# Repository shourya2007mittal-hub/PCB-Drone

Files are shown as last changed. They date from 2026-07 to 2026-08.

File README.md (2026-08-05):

# PCB-Drone



So I made a custom PCB based on Esp32 . It holds an IMU and a Barometer for control . It has a normal 4 Motor Layout 2 motors will move  clock wise and 2 will be  anti-clock wise direction. Same direction motor will be diagonally apposite to each other. It have  used a 3.7V battery for power and a boot converter so that I can provide 5V to the Motors as we are using  ESP32 so we could controle it by our phone through bluetooth  .I have also design a web based controller , So that you could connect and controle the Bionic-Bird through your phone.

So I have a USB-C and battery pin (3.7V) then it is commonly connected to power with diodes for reverse polarity then It goes to a 3.3V voltage regulator (AP63203WU) with Reverse Polarity Protection and Pi Filter for sensors and ESp32  . and 5V regulator (MT3608) for motors . Then 3.3v it goes to IMU (MPU-6050) Barometer (BMP280) then through I2c these data are transferred to ESP32 where computation takes place and through Logic-Level Enhancement Mode MOSFET(AO3400A) circuit it amplifies  the PWN signal to 5V for the motors to work  

## Features

- Base on ESP32 Module
- Has IMU (MPU_6050)
- Has a Barometer (BMP280)
- Uses 4 8520 Motors 

## Components BOM

### 1. JLCPCB Manufacturing & Assembly Services
| Charge Description | Details / Notes | Cost ($) |
| :--- | :--- | :---: |
| **Components Cost** | 26 Matched Part Lines | $64.35 |
| **Setup Fee** | SMT Line Assembly Setup | $25.56 |
| **Stencil Fee** | SMT Laser Stencil | $8.21 |
| **Feeders Loading Fee** | Component Feeder Setup | $33.66 |
| **SMT Assembly** | Automated SMT Placement | $1.23 |
| **Hand-Soldering Labor Fee** | Through-hole / Manual Soldering | $3.58 |
| **Manual Assembly** | Specialized Component Insertion | $0.46 |
| **X-Ray Inspection** | BGA / QFN Joint Verification | $3.28 |
| **Packaging Fee** | Protective ESD Packaging | $0.50 |
| **Engineering Fee** | DFM / CAM File Verification | $4.00 |
| **Via Covering** | Tent / Plugged Vias | $0.00 |
| **PCB Fabrication Board Fee** | Raw Printed Circuit Board Cost | $9.90 |
| **PCB Shipping** | Express Courier to Destination | $11.53 |

---

### 2. External Hardware & Accessories
| Item | Description / Details | Qty | Link | Cost ($) |
| :--- | :--- | :---: | :---: | :---: |
| **8520 Coreless Motor** | Magnetic Micro Coreless Motor Set (2x CW, 2x CCW) | 1 Set | [Robu.in Link](https://robu.in/product/8520-magnetic-micro-coreless-motor-for-micro-quadcopters-2xcw-2xccw/) | $4.93 |
| **3.7V Battery** | KP Original 802540 1200mAh Single-Cell LiPo Battery | 1 Pcs | [Zbotic Link](https://zbotic.in/product/kp-original-802540-1200mah-3-7vsingle-cell-rechargeable-lipo-battery/) | $3.46 |

---

## 🧩 Complete Component Bill of Materials (BOM)

| Designator | Description / Value | Footprint | Qty | Price ($) | Part Details / Link |
| :--- | :--- | :--- | :---: | :---: | :--- |
| **C2** | 47uF 450V Electrolytic | 0201 | 2 | $1.333 | [KM476M450K25RR0VH2FP0](https://jlcpcb.com/partdetail/3127-KM476M450K25RR0VH2FP0/C2746) |
| **C3, C11, C18, C19** | 10uF 6.3V X5R | 0201 | 40 | $1.172 | [CL10A106MQ8NNNC](https://jlcpcb.com/partdetail/2043-CL10A106MQ8NNNC/C1691) |
| **C4, C13, C14** | 100nF 10V X5R | 0201 | 40 | $0.292 | [GRM033R61A104KE15D](https://jlcpcb.com/partdetail/MurataElectronics-GRM033R61A104KE15D/C76934) |
| **C5, C6** | 22uF 10V X5R | 0201 | 16 | $5.0256 | [1206X226K100NT](https://jlcpcb.com/partdetail/2211-1206X226K100NT/C1859) |
| **C9, C10, C12** | 0.1uF 10V X5R | 0201 | 40 | $0.236 | [0201X104K100NT](https://jlcpcb.com/partdetail/270391-0201X104K100NT/C284966) |
| **C7, C8, C15, C16** | 50nF Capacitors | 0201 | 8 | $6.532 | [LHC503SA2K0042NWB](https://jlcpcb.com/partdetail/launchip-LHC503SA2K0042NWB/C49233446) |
| **C1X1 - C6X1** | 1uF / 100nF Caps | 0805 | 22 | $0.3982 | [GZ2012D220TF](https://jlcpcb.com/partdetail/Sunlord-GZ2012D220TF/C1009) |
| **D1, D3** | LED Indicator | 0201 | 8 | $0.5448 | [XL0201SURC](https://jlcpcb.com/partdetail/XINGLIGHT-XL0201SURC/C3646923) |
| **D2** | Diode | 0201 | 2 | $0.3944 | [HIR204C](https://jlcpcb.com/partdetail/EverlightElec-HIR204C/C5118) |
| **D4, D5, D6, D7** | Schottky Diode | 0201 | 20 | $0.038 | [0201WMJ010JTEE](https://jlcpcb.com/partdetail/25797-0201WMJ010JTEE/C25054) |
| **F1** | Polyfuse | 0201 | 20 | $0.038 | [0201WMJ010JTEE](https://jlcpcb.com/partdetail/25797-0201WMJ010JTEE/C25054) |
| **D8** | 1N4001 Diode | DO-41 | 4 | $0.0776 | [1N4001](https://jlcpcb.com/partdetail/49200031-1N4001/C47018536) |
| **L1** | 2.2uH Power Inductor | 0201 | 20 | $0.750 | [CY43_22UH](https://jlcpcb.com/partdetail/SHOUHAN-CY43_22UH/C2929416) |
| **L2** | 4.7uH Inductor | 0603 | 20 | $0.414 | [SDFL1608Q4R7KTF](https://jlcpcb.com/partdetail/Sunlord-SDFL1608Q4R7KTF/C1034) |
| **Q1** | AO3401A P-Ch MOSFET | SOT-23 | 6 | $0.5688 | [AO3401A](https://jlcpcb.com/partdetail/Alpha_OmegaSemicon-AO3401A/C15127) |
| **Q2, Q3, Q4, Q5** | AO3400A N-Ch MOSFET | SOT-23 | 12 | $1.008 | [AO3400A](https://jlcpcb.com/partdetail/Alpha_OmegaSemicon-AO3400A/C20917) |
| **R1, R2** | 33 Ohm Resistor | 0201 | 20 | $0.062 | [0201WMJ0330TEE](https://jlcpcb.com/partdetail/416306-0201WMJ0330TEE/C423356) |
| **R3, R4** | 50K Resistor | 0201 | 6 | $0.7632 | [GL3549](https://jlcpcb.com/partdetail/10622-GL3549/C10083) |
| **R6, R7** | 1K Resistor | 0201 | 20 | $0.050 | [0201WMF1001TEE](https://jlcpcb.com/partdetail/259895-0201WMF1001TEE/C270365) |
| **R8, R10, R12, R14** | 100 Ohm Resistor | 0201 | 20 | $0.056 | [RC01W1000FT](https://jlcpcb.com/partdetail/288566-RC01W1000FT/C304499) |
| **R9, R11, R13, R15** | 10K Resistor | 0201 | 20 | $0.086 | [CR0201FH1002G](https://jlcpcb.com/partdetail/LIZElec-CR0201FH1002G/C100126) |
| **R1_1, R2_1** | 10K / 100 Ohm | 0805 | 6 | $0.5364 | [FSMD050_0805R](https://jlcpcb.com/partdetail/FuzetecTech-FSMD050_0805R/C181350) |
| **U1** | MT3608 Boost Regulator | SOT-23-6 | 5 | $0.5665 | [MT3608](https://jlcpcb.com/partdetail/XI_AN_AerosemiTech-MT3608/C84817) |
| **U2** | AP63203WU Buck Regulator | TSOT-23-6 | 2 | $2.2268 | [AP63203QWU7](https://jlcpcb.com/partdetail/DiodesIncorporated-AP63203QWU7/C5248536) |
| **U3** | MPU-6050 6-Axis IMU Sensor | QFN-24 | 2 | $29.0122 | [MPU6050](https://jlcpcb.com/partdetail/TDKInvenSense-MPU6050/C24112) |
| **U4** | BMP280 Barometric Pressure Sensor | LGA-8 | 2 | $5.2442 | [BMP388 / BMP280](https://jlcpcb.com/partdetail/BoschSensortec-BMP388/C779278) |
| **U5** | ESP32-S3-WROOM-1 Wi-Fi/BT MCU | Module | 2 | $10.327 | [ESP32_S3_WROOM_1N16R8](https://jlcpcb.com/partdetail/3198300-ESP32_S3_WROOM_1N16R8/C2913202) |
| **J1** | USB Type-C Receptacle 16P | USB-C | - | - | Hand Assembly / Manual |
| **J2** | Pin Header Connector | JST-EH 2.5mm | - | - | Through Hole |
| **M1, M2, M3, M4** | Motor Drive Outputs | 1x02 Pin Header | - | - | Through Hole |
| **SW1, SW2** | Push Button Switches | PTS810 | - | - | SMT / Manual |

---

---

## 📊 Summary & Total Cost

| Category | Total Cost (USD) |
| :--- | :---: |
| **PCBA Manufacturing & Components (26 Items)** | **$154.73** |
| **PCB Shipping (JLCPCB)** | **$11.53** |
| **External Motors (8520 Coreless Motor Set)** | **$4.93** |
| **3.7V LiPo Battery (1200mAh)** | **$3.46** |
| **Grand Total** | **`$174.65`** |

### Schematic



###  PCB Design




###  3D Design



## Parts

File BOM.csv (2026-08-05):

Top design | Comment | footprint | quantitty | total price | product link
Top Designator | Comment | Footprint | Qty | Total Price ($) | Product link
C2 | 47uf | 0201 | 2 | 1.333 | https://jlcpcb.com/partdetail/3127-KM476M450K25RR0VH2FP0/C2746
C3 | 10uf | 0201 | 20 | 0.586 | https://jlcpcb.com/partdetail/2043-CL10A106MQ8NNNC/C1691
C11,C18,C19 | 10uf | 0201 | 20 | 0.586 | https://jlcpcb.com/partdetail/2043-CL10A106MQ8NNNC/C1691
C4 | 100nf | 0201 | 20 | 0.146 | https://jlcpcb.com/partdetail/MurataElectronics-GRM033R61A104KE15D/C76934
C13,C14 | 100nf | 0201 | 20 | 0.146 | https://jlcpcb.com/partdetail/MurataElectronics-GRM033R61A104KE15D/C76934
C5 | 22u | 0201 | 8 | 2.5128 | https://jlcpcb.com/partdetail/2211-1206X226K100NT/C1859
C6 | 22uf | 0201 | 8 | 2.5128 | https://jlcpcb.com/partdetail/2211-1206X226K100NT/C1859
C10,C9 | 0.1uf | 0201 | 20 | 0.118 | https://jlcpcb.com/partdetail/270391-0201X104K100NT/C284966
C12 | 0.1uf | 0201 | 20 | 0.118 | https://jlcpcb.com/partdetail/270391-0201X104K100NT/C284966
C15,C16,C7,C8 | 50nf | 0201 | 8 | 6.532 | https://jlcpcb.com/partdetail/launchip-LHC503SA2K0042NWB/C49233446
C1X1,C2X1,C3X1,C4X1,C5(1UF)1,C6(100NF)1 | C | 0805 | 22 | 0.3982 | https://jlcpcb.com/partdetail/Sunlord-GZ2012D220TF/C1009
D1,D3 | LED | 0201 | 8 | 0.5448 | https://jlcpcb.com/partdetail/XINGLIGHT-XL0201SURC/C3646923
D2 | D | 0201 | 2 | 0.3944 | https://jlcpcb.com/partdetail/EverlightElec-HIR204C/C5118
D4,D5,D6,D7 | D_Schottky | 0201 | 20 | 0.038 | https://jlcpcb.com/partdetail/25797-0201WMJ010JTEE/C25054
F1 | Polyfuse | 0201 | 20 | 0.038 | https://jlcpcb.com/partdetail/25797-0201WMJ010JTEE/C25054
D8 | 1N4001 | D_DO-41_SOD81_P5.08mm_Vertical_KathodeUp | 4 | 0.0776 | https://jlcpcb.com/partdetail/49200031-1N4001/C47018536
L1 | 2.2uh | 0201 | 20 | 0.75 | https://jlcpcb.com/partdetail/SHOUHAN-CY43_22UH/C2929416
L2 | 4.7uf | 0603 | 20 | 0.414 | https://jlcpcb.com/partdetail/Sunlord-SDFL1608Q4R7KTF/C1034
Q1 | AO3401A | SOT-23 | 6 | 0.5688 | https://jlcpcb.com/partdetail/Alpha_OmegaSemicon-AO3401A/C15127
Q2,Q3,Q4,Q5 | AO3400A | SOT-23 | 12 | 1.008 | https://jlcpcb.com/partdetail/Alpha_OmegaSemicon-AO3400A/C20917
R1,R2 | 33R | 0201 | 20 | 0.062 | https://jlcpcb.com/partdetail/416306-0201WMJ0330TEE/C423356
R3,R4 | 50K | 0201 | 6 | 0.7632 | https://jlcpcb.com/partdetail/10622-GL3549/C10083
R6,R7 | 1K | 0201 | 20 | 0.05 | https://jlcpcb.com/partdetail/259895-0201WMF1001TEE/C270365
R10,R12,R14,R8 | 100R | 0201 | 20 | 0.056 | https://jlcpcb.com/partdetail/288566-RC01W1000FT/C304499
R11,R13,R15,R9 | 10KR | 0201 | 20 | 0.086 | https://jlcpcb.com/partdetail/LIZElec-CR0201FH1002G/C100126
R1(10K)1,R2(100R)1 | R | 0805 | 6 | 0.5364 | https://jlcpcb.com/partdetail/FuzetecTech-FSMD050_0805R/C181350
U1 | MT3608 | SOT-23-6 | 5 | 0.5665 | https://jlcpcb.com/partdetail/XI_AN_AerosemiTech-MT3608/C84817
U2 | AP63203WU | TSOT-23-6 | 2 | 2.2268 | https://jlcpcb.com/partdetail/DiodesIncorporated-AP63203QWU7/C5248536
U3 | MPU-6050 | InvenSense_QFN-24_4x4mm_P0.5mm | 2 | 29.0122 | https://jlcpcb.com/partdetail/TDKInvenSense-MPU6050/C24112
U4 | BMP280 | Bosch_LGA-8_2x2.5mm_P0.65mm_ClockwisePinNumbering | 2 | 5.2442 | https://jlcpcb.com/partdetail/BoschSensortec-BMP388/C779278
U5 | ESP32-S3-WROOM-1 | ESP32-S3-WROOM-1 | 2 | 10.327 | https://jlcpcb.com/partdetail/3198300-ESP32_S3_WROOM_1N16R8/C2913202
J1 | USB_C_Receptacle_USB2.0_16P | USB_C_Receptacle_G-Switch_GT-USB-7010ASV
J2 | Conn_01x02_Pin | JST_EH_B2B-EH-A_1x02_P2.50mm_Vertical
M1,M2,M3,M4 | Motor_DC | PinHeader_1x02_P2.54mm_Vertical
SW1,SW2 | SW_Push | SW_SPST_PTS810
Components (26 items) | JLCPCB Assembly Order Components | - | 26 | 64.35 | -
Setup Fee | Assembly Setup Fee | - | 1 | 25.56 | -
Stencil | SMT Stencil Fee | - | 1 | 8.21 | -
Feeders Loading fee | Feeder Loading Fee | - | 1 | 33.66 | -
SMT Assembly | SMT Assembly Fee | - | 1 | 1.23 | -
Hand-soldering labor fee | Labor Fee | - | 1 | 3.58 | -
Manual Assembly | Manual Assembly Fee | - | 1 | 0.46 | -
X-Ray Inspection | Inspection Fee | - | 1 | 3.28 | -
Packaging fee | Packaging Fee | - | 1 | 0.5 | -
Engineering fee | Engineering Fee | - | 1 | 4.0 | -
Via Covering | Via Covering Fee | - | 1 | 0.0 | -
Board | PCB Manufacturing Board Fee | - | 1 | 9.9 | -
PCB Shipping |  |  | - | 11.53 | JLCPCB
8520 Coreless Motor |  |  | 1 Set (of 4) | 4.93 | https://robu.in/product/8520-magnetic-micro-coreless-motor-for-micro-quadcopters-2xcw-2xccw/?gad_source=1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
3.7V battery |  |  | 1 | 3.46 | https://zbotic.in/product/kp-original-802540-1200mah-3-7vsingle-cell-rechargeable-lipo-battery/?gad_source=1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
Total |  |  |  | 174.65

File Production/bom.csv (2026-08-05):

Designator | Footprint | Quantity | Value | LCSC Part #
C10, C9 | 0201 | 2 | 0.1uf
C11, C18, C19 | 0201 | 3 | 10 uf
C12 | 0201 | 1 | 0.1 uf
C13, C14 | 0201 | 2 | 100 nf
C15, C16, C7, C8 | 0201 | 4 | 50nf
C1X1, C2X1, C3X1, C4X1, C5(1UF)1, C6(100NF)1 | 0805 | 6 | C
C2 | 0201 | 1 | 47uf
C3 | 0201 | 1 | 10uf
C4 | 0201 | 1 | 100nf
C5 | 0201 | 1 | 22u
C6 | 0201 | 1 | 22uf
D1, D3 | 0201 | 2 | LED
D2 | 0201 | 1 | D
D4, D5, D6, D7 | 0201 | 4 | D_Schottky
D8 | D_DO-41_SOD81_P5.08mm_Vertical_KathodeUp | 1 | 1N4001
F1 | 0201 | 1 | Polyfuse
J1 | USB_C_Receptacle_G-Switch_GT-USB-7010ASV | 1 | USB_C_Receptacle_USB2.0_16P
J2 | JST_EH_B2B-EH-A_1x02_P2.50mm_Vertical | 1 | Conn_01x02_Pin
L1 | 0201 | 1 | 2.2uh
L2 | 0603 | 1 | 4.7uf
M1, M2, M3, M4 | PinHeader_1x02_P2.54mm_Vertical | 4 | Motor_DC
Q1 | SOT-23 | 1 | AO3401A
Q2, Q3, Q4, Q5 | SOT-23 | 4 | AO3400A
R1, R2 | 0201 | 2 | 33 R
R1(10K)1, R2(100R)1 | 0805 | 2 | R
R10, R12, R14, R8 | 0201 | 4 | 100R
R11, R13, R15, R9 | 0201 | 4 | 10K R
R3, R4 | 0201 | 2 | 50K
R6, R7 | 0201 | 2 | 1K
SW1, SW2 | SW_SPST_PTS810 | 2 | SW_Push
U1 | SOT-23-6 | 1 | MT3608
U2 | TSOT-23-6 | 1 | AP63203WU
U3 | InvenSense_QFN-24_4x4mm_P0.5mm | 1 | MPU-6050
U4 | Bosch_LGA-8_2x2.5mm_P0.65mm_ClockwisePinNumbering | 1 | BMP280
U5 | ESP32-S3-WROOM-1 | 1 | ESP32-S3-WROOM-1

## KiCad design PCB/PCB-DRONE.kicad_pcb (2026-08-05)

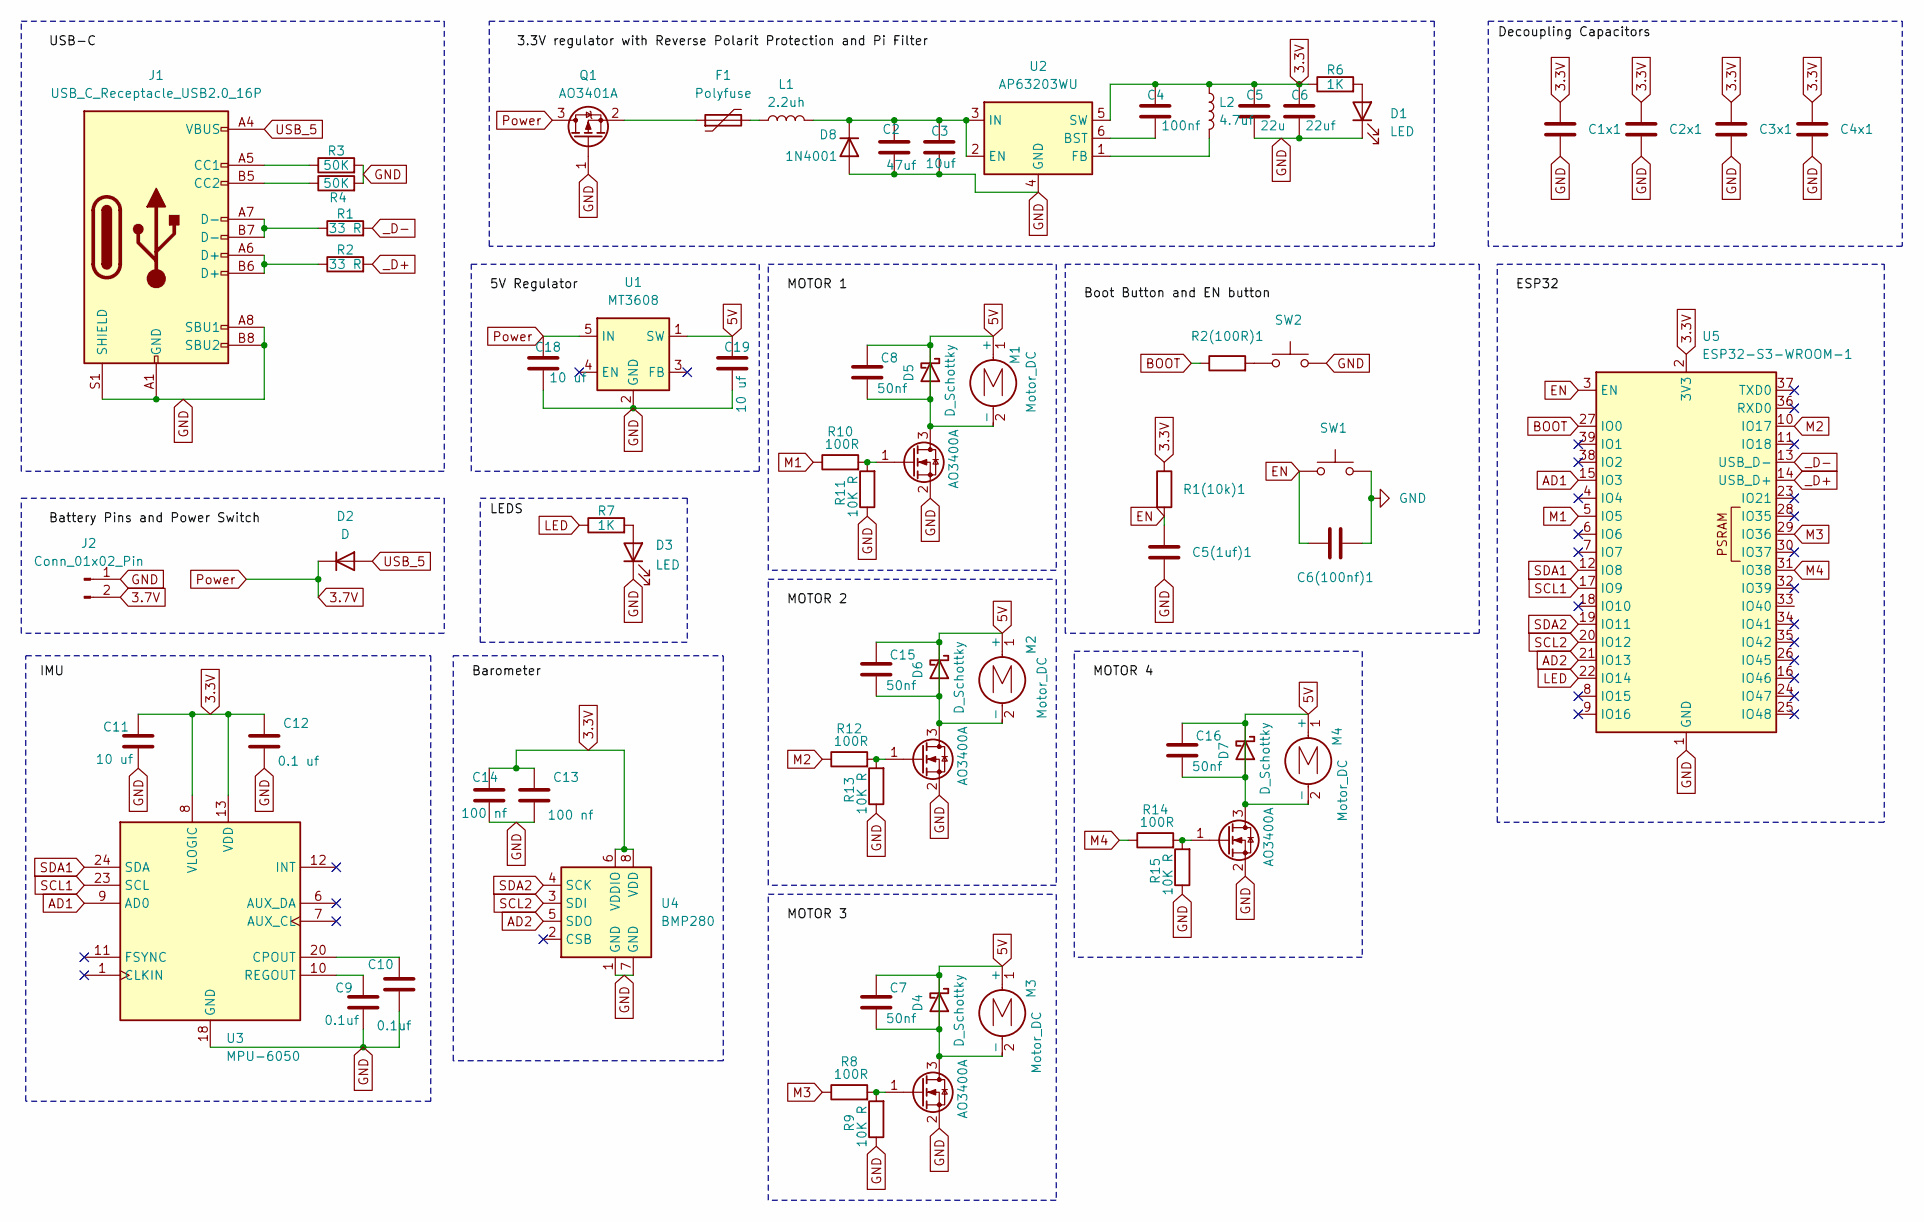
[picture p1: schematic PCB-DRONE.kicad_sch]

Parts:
C1x1, C2x1, C3x1, C4x1, C5(1uf)1, C6(100nf)1: C; C_0805_2012Metric
C2: 47uf; C_0201_0603Metric
C3: 10uf; C_0201_0603Metric
C4: 100nf; C_0201_0603Metric
C5: 22u; C_0201_0603Metric
C6: 22uf; C_0201_0603Metric
C7, C8, C15, C16: 50nf; C_0201_0603Metric
C9, C10: 0.1uf; C_0201_0603Metric
C11, C18, C19: 10 uf; C_0201_0603Metric
C12: 0.1 uf; C_0201_0603Metric
C13, C14: 100 nf; C_0201_0603Metric
D1, D3: LED; LED_0201_0603Metric
D2: D; D_0201_0603Metric
D4, D5, D6, D7: D_Schottky; D_0201_0603Metric
D8: 1N4001; D_DO-41_SOD81_P5.08mm_Vertical_KathodeUp
F1: Polyfuse; C_0201_0603Metric
J1: USB_C_Receptacle_USB2.0_16P; USB_C_Receptacle_G-Switch_GT-USB-7010ASV
J2: Conn_01x02_Pin; JST_EH_B2B-EH-A_1x02_P2.50mm_Vertical
L1: 2.2uh; L_0201_0603Metric
L2: 4.7uf; L_0603_1608Metric
M1, M2, M3, M4: Motor_DC; PinHeader_1x02_P2.54mm_Vertical
Q1: AO3401A; SOT-23
Q2, Q3, Q4, Q5: AO3400A; SOT-23
R1, R2: 33 R; R_0201_0603Metric_Pad0.64x0.40mm_HandSolder
R1(10k)1, R2(100R)1: R; R_0805_2012Metric
R3, R4: 50K; R_0201_0603Metric_Pad0.64x0.40mm_HandSolder
R6, R7: 1K; R_0201_0603Metric_Pad0.64x0.40mm_HandSolder
R8, R10, R12, R14: 100R; R_0201_0603Metric
R9, R11, R13, R15: 10K R; R_0201_0603Metric
SW1, SW2: SW_Push; SW_SPST_PTS810
U1: MT3608; SOT-23-6
U2: AP63203WU; TSOT-23-6
U3: MPU-6050; InvenSense_QFN-24_4x4mm_P0.5mm
U4: BMP280; Bosch_LGA-8_2x2.5mm_P0.65mm_ClockwisePinNumbering
U5: ESP32-S3-WROOM-1

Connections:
3.3V: C1x1.1, C2x1.1, C3x1.1, C4.1, C4x1.1, C5.1, C6.1, C11.1, C12.1, C13.1, C14.1, L2.1, R1(10k)1.1, R6.1, U2.5 (SW), U3.8 (VLOGIC), U3.13 (VDD), U4.6 (VDDIO), U4.8 (VDD), U5.2 (3V3)
3.7V: C18.1, D2.1 (K), J2.2, Q1.3 (D), U1.5 (IN)
5V: C7.1, C7.2, C8.1, C8.2, C15.1, C15.2, C16.1, C16.2, C19.1, D4.1 (K), D4.2 (A), D5.1 (K), D5.2 (A), D6.1 (K), D6.2 (A), D7.1 (K), D7.2 (A), M1.1 (+), M1.2 (-), M2.1 (+), M2.2 (-), M3.1 (+), M3.2 (-), M4.1 (+), M4.2 (-), Q2.3 (D), Q3.3 (D), Q4.3 (D), Q5.3 (D), U1.1 (SW)
AD1: U3.9 (AD0), U5.15 (IO3)
AD2: U4.5 (SDO), U5.21 (IO13)
BOOT: R2(100R)1.1, U5.27 (IO0)
EN: C5(1uf)1.1, C6(100nf)1.1, R1(10k)1.2, SW1.1, U5.3 (EN)
GND: C1x1.2, C2.2, C2x1.2, C3.2, C3x1.2, C4x1.2, C5.2, C5(1uf)1.2, C6.2, C6(100nf)1.2, C9.2, C10.2, C11.2, C12.2, C13.2, C14.2, C18.2, C19.2, D1.1 (K), D3.1 (K), D8.2 (A), J1.A1 (GND), J1.A8 (SBU1), J1.A12 (GND), J1.B1 (GND), J1.B8 (SBU2), J1.B12 (GND), J1.S1 (SHIELD), J2.1, Q1.1 (G), Q2.2 (S), Q3.2 (S), Q4.2 (S), Q5.2 (S), R3.2, R4.2, R9.1, R11.1, R13.1, R15.1, SW1.2, SW2.2, U1.2 (GND), U2.4 (GND), U3.18 (GND), U4.1 (GND), U4.7 (GND), U5.1 (GND), U5.40 (GND), U5.41 (GND)
LED: R7.1, U5.22 (IO14)
M1: R10.1, U5.5 (IO5)
M2: R12.1, U5.10 (IO17)
M3: R8.1, U5.29 (IO36)
M4: R14.1, U5.31 (IO38)
unnamed: D1.2 (A), R6.2
unnamed: D3.2 (A), R7.2
unnamed: C2.1, C3.1, D8.1 (K), L1.2, U2.2 (EN), U2.3 (IN)
unnamed: F1.2, L1.1
unnamed: J1.A5 (CC1), R3.1
unnamed: J1.B5 (CC2), R4.1
unnamed: J1.A6 (D+), J1.B6 (D+), R2.1
unnamed: J1.A7 (D-), J1.B7 (D-), R1.1
unnamed: F1.1, Q1.2 (S)
unnamed: Q2.1 (G), R8.2, R9.2
unnamed: Q3.1 (G), R10.2, R11.2
unnamed: Q4.1 (G), R12.2, R13.2
unnamed: Q5.1 (G), R14.2, R15.2
unnamed: R2(100R)1.2, SW2.1
unnamed: C4.2, U2.6 (BST)
unnamed: L2.2, U2.1 (FB)
unnamed: C10.1, U3.20 (CPOUT)
unnamed: C9.1, U3.10 (REGOUT)
SCL1: U3.23 (SCL), U5.17 (IO9)
SCL2: U4.3 (SDI), U5.20 (IO12)
SDA1: U3.24 (SDA), U5.12 (IO8)
SDA2: U4.4 (SCK), U5.19 (IO11)
USB_5: D2.2 (A), J1.A4 (VBUS), J1.A9 (VBUS), J1.B4 (VBUS), J1.B9 (VBUS)
_D+: R2.2, U5.14 (USB_D+)
_D-: R1.2, U5.13 (USB_D-)

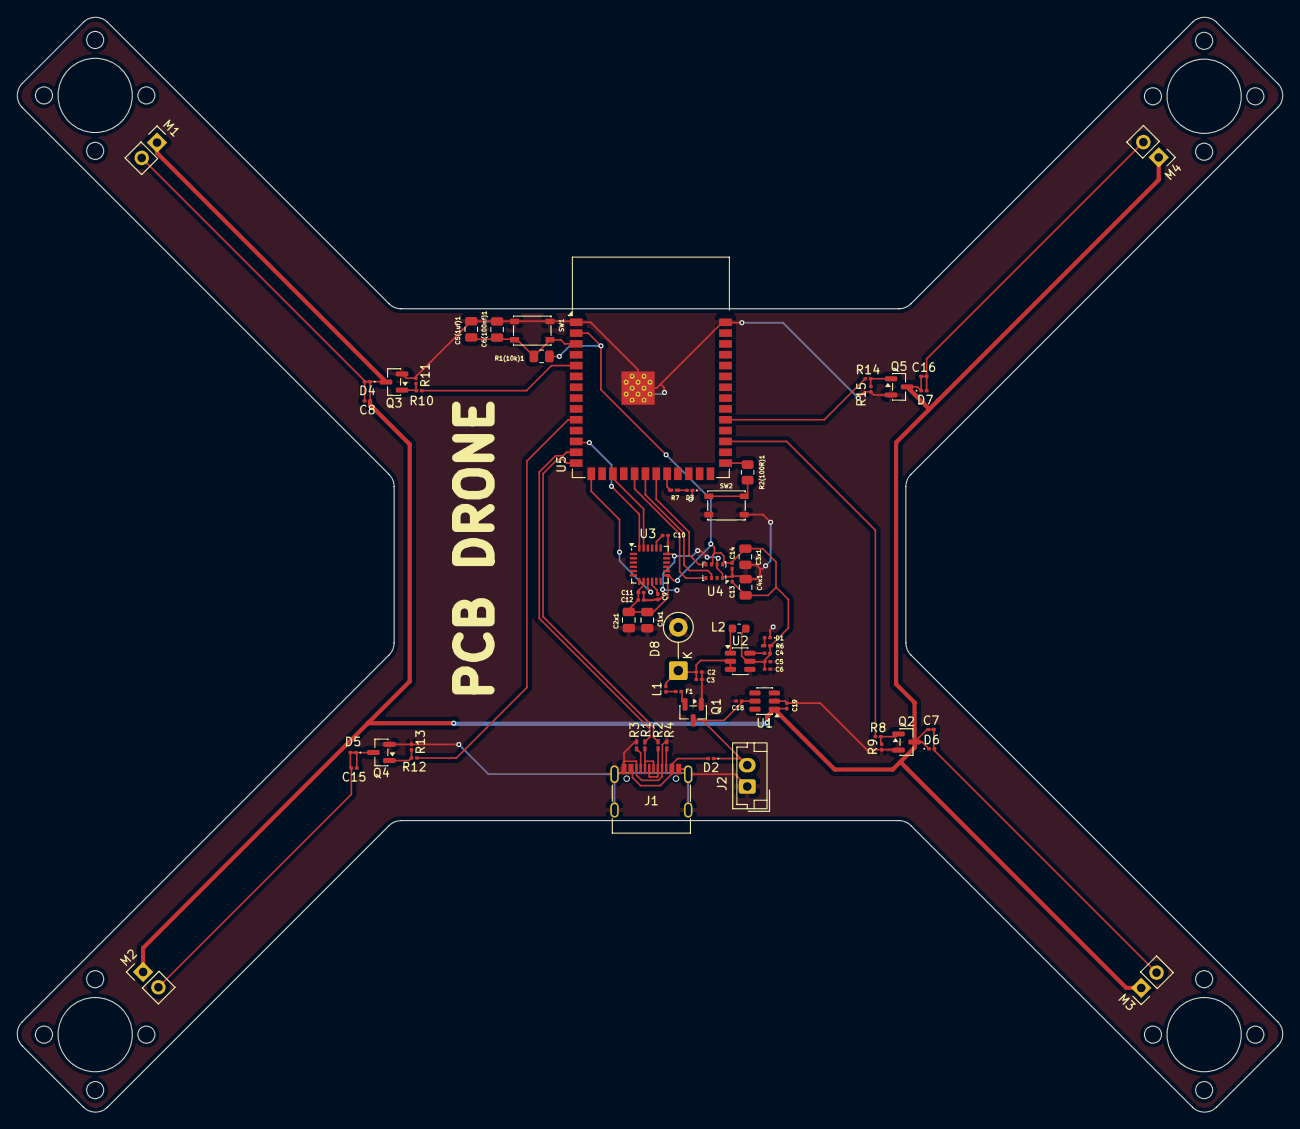
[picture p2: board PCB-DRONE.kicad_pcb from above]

Board: 2 copper layers, 148.3 x 128.3 mm, 68 parts (0 on the bottom side), 38 nets.

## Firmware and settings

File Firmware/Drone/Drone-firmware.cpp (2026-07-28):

#include <Wire.h>
#include <Adafruit_MPU6050.h>
#include <Adafruit_BMP280.h>
#include <NimBLEDevice.h>

// --- PIN DEFINITIONS ---
#define PIN_M1 5
#define PIN_M2 17
#define PIN_M3 36
#define PIN_M4 37
#define PIN_LED 14

#define SDA_IMU 12
#define SCL_IMU 17 // Shared pin in schematic, note hardware conflict if both I2C buses run separately!
#define SDA_BARO 11
#define SCL_BARO 10

// PWM Setup
#define PWM_FREQ 20000 // 20kHz for brushed DC motor noise reduction
#define PWM_RES 8      // 0-255 duty cycle

// Bluetooth BLE UUIDs
#define SERVICE_UUID        "4fafc201-1fb5-459e-8fcc-c5c9c331914b"
#define CHARACTERISTIC_UUID "beb5483e-36e1-4688-b7f5-ea07361b26a8"

// Hardware Sensors
TwoWire I2C_IMU = TwoWire(0);
TwoWire I2C_BARO = TwoWire(1);
Adafruit_MPU6050 mpu;
Adafruit_BMP280 bmp(&I2C_BARO);

// Control Input Variables (from BLE)
volatile float req_throttle = 0; // 0 to 255
volatile float req_roll = 0;     // -30 to +30 deg
volatile float req_pitch = 0;    // -30 to +30 deg
volatile float req_yaw = 0;      // deg/s
volatile bool armed = false;

// Sensor Data
float roll_angle = 0, pitch_angle = 0;
float gyro_x = 0, gyro_y = 0, gyro_z = 0;
unsigned long last_time = 0;

// PID Gains
float kp_roll = 1.3, ki_roll = 0.01, kd_roll = 0.5;
float kp_pitch = 1.3, ki_pitch = 0.01, kd_pitch = 0.5;

// PID Variables
float error_roll, prev_error_roll, integral_roll;
float error_pitch, prev_error_pitch, integral_pitch;

// BLE Callbacks
class ServerCallbacks: public NimBLEServerCallbacks {
    void onConnect(NimBLEServer* pServer) {
        digitalWrite(PIN_LED, HIGH);
    }
    void onDisconnect(NimBLEServer* pServer) {
        digitalWrite(PIN_LED, LOW);
        armed = false; // Emergency stop on disconnect
    }
};

class CommandCallbacks: public NimBLECharacteristicCallbacks {
    void onWrite(NimBLECharacteristic *pCharacteristic) {
        std::string rxValue = pCharacteristic->getValue();
        if (rxValue.length() >= 5) {
            uint8_t cmd = rxValue[0];
            armed = (cmd == 1);
            req_throttle = (uint8_t)rxValue[1];
            req_roll = (int8_t)rxValue[2];     // Sent as offset -128 to 127
            req_pitch = (int8_t)rxValue[3];
            req_yaw = (int8_t)rxValue[4];
        }
    }
};

void setup() {
    Serial.begin(115200);
    pinMode(PIN_LED, OUTPUT);

    // PWM Setup for Motors
    ledcAttach(PIN_M1, PWM_FREQ, PWM_RES);
    ledcAttach(PIN_M2, PWM_FREQ, PWM_RES);
    ledcAttach(PIN_M3, PWM_FREQ, PWM_RES);
    ledcAttach(PIN_M4, PWM_FREQ, PWM_RES);

    // Stop Motors
    stopMotors();

    // Init I2C
    I2C_IMU.begin(SDA_IMU, SCL_IMU, 400000);
    I2C_BARO.begin(SDA_BARO, SCL_BARO, 100000);

    // Init MPU6050
    if (!mpu.begin(0x68, &I2C_IMU)) {
        Serial.println("Failed to find MPU6050 chip");
    }

    // Init BMP280
    if (!bmp.begin(0x76)) {
        Serial.println("Failed to find BMP280 chip");
    }

    // Bluetooth setup
    NimBLEDevice::init("PCB_Drone_ESP32");
    NimBLEServer *pServer = NimBLEDevice::createServer();
    pServer->setCallbacks(new ServerCallbacks());
    
    NimBLEService *pService = pServer->createService(SERVICE_UUID);
    NimBLECharacteristic *pCharacteristic = pService->createCharacteristic(
        CHARACTERISTIC_UUID,
        NIMBLE_PROPERTY::WRITE | NIMBLE_PROPERTY::WRITE_NR
    );
    pCharacteristic->setCallbacks(new CommandCallbacks());
    pService->start();

    NimBLEAdvertising *pAdvertising = NimBLEDevice::getAdvertising();
    pAdvertising->addServiceUUID(SERVICE_UUID);
    pAdvertising->start();

    last_time = micros();
}

void loop() {
    // 1. Time delta
    unsigned long current_time = micros();
    float dt = (current_time - last_time) / 1000000.0;
    last_time = current_time;

    // 2. Read Sensors
    sensors_event_t a, g, temp;
    mpu.getEvent(&a, &g, &temp);

    // Calculate Accelerometer Angles
    float accel_roll = atan2(a.acceleration.y, a.acceleration.z) * 57.2958;
    float accel_pitch = atan2(-a.acceleration.x, sqrt(a.acceleration.y * a.acceleration.y + a.acceleration.z * a.acceleration.z)) * 57.2958;

    // Complementary Filter
    roll_angle = 0.96 * (roll_angle + g.gyro.x * dt * 57.2958) + 0.04 * accel_roll;
    pitch_angle = 0.96 * (pitch_angle + g.gyro.y * dt * 57.2958) + 0.04 * accel_pitch;

    // 3. PID Calculations
    if (armed && req_throttle > 15) {
        // Roll PID
        error_roll = req_roll - roll_angle;
        integral_roll += error_roll * dt;
        float derivative_roll = (error_roll - prev_error_roll) / dt;
        float out_roll = (kp_roll * error_roll) + (ki_roll * integral_roll) + (kd_roll * derivative_roll);
        prev_error_roll = error_roll;

        // Pitch PID
        error_pitch = req_pitch - pitch_angle;
        integral_pitch += error_pitch * dt;
        float derivative_pitch = (error_pitch - prev_error_pitch) / dt;
        float out_pitch = (kp_pitch * error_pitch) + (ki_pitch * integral_pitch) + (kd_pitch * derivative_pitch);
        prev_error_pitch = error_pitch;

        // Mixer
        int m1 = req_throttle + out_pitch + out_roll; // Front Left
        int m4 = req_throttle + out_pitch - out_roll; // Front Right
        int m2 = req_throttle - out_pitch + out_roll; // Rear Left
        int m3 = req_throttle - out_pitch - out_roll; // Rear Right

        // Drive Motors
        ledcWrite(PIN_M1, constrain(m1, 0, 255));
        ledcWrite(PIN_M2, constrain(m2, 0, 255));
        ledcWrite(PIN_M3, constrain(m3, 0, 255));
        ledcWrite(PIN_M4, constrain(m4, 0, 255));
    } else {
        stopMotors();
        resetPID();
    }

    delay(4); // ~250 Hz loop
}

void stopMotors() {
    ledcWrite(PIN_M1, 0);
    ledcWrite(PIN_M2, 0);
    ledcWrite(PIN_M3, 0);
    ledcWrite(PIN_M4, 0);
}

void resetPID() {
    integral_roll = 0; prev_error_roll = 0;
    integral_pitch = 0; prev_error_pitch = 0;
}
